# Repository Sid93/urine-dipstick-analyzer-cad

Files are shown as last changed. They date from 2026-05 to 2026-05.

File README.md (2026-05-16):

# Urine Dipstick Analyzer

> Open-source urine dipstick analyzer using ESP32-S3 + computer vision.







## What it does

A self-contained device that reads off-the-shelf 10-parameter urine dipsticks
(glucose, ketones, bilirubin, blood, pH, protein, urobilinogen, nitrite,
leukocytes, specific gravity) using a calibrated colorimetric pipeline. A
white + UV LED ring illuminates the strip, an OV2640 camera captures the
reaction pads, and an ESP32-S3 runs per-pad ROI analysis against a factory
calibration set anchored to an X-Rite ColorChecker Nano. Results are shown
on a 2.4" ILI9341 display, logged to SD, and optionally streamed over Wi-Fi.
Total BOM is approximately USD 330 in single-unit quantities.

## Photos and drawings

Mechanical drawings (PDF) for every printed/machined part live in
[`drawings/`](drawings/). 3D models in STEP and STL are in the project root
(`im_enclosure_base.*`, `enclosure_cover.*`, `camera_led_mount.*`,
`scanner_mount.*`, `vent_grill.*`, `im_tray.*`, `internal_wire_frame.*`).
Schematic render: [`schematic_render.png`](schematic_render.png).

## Hardware overview

| Subsystem | Part | Notes |
|---|---|---|
| MCU | ESP32-S3-DevKitC-1-N8R8 | 8 MB flash, 8 MB OPI PSRAM, dual-core |
| Camera | OV2640 (DVP) | hardware DVP on ESP32-S3 |
| Display | 2.4" ILI9341 SPI TFT | 320 x 240, Adafruit_ILI9341 driver |
| Illumination | White + 365 nm UV LEDs | constant-current via PMOS |
| Strip transport | NEMA-8 stepper + A4988 | AccelStepper-driven |
| Environment | SHT31 (T/RH), BH1750 (lux), DS3231 (RTC) | I2C bus |
| Power | Single 18650 + MCP73833 charger + MAX17048 fuel gauge | 3.7 V Li-ion |
| Enclosure | FDM PETG, M2.5 fasteners | STEP files in repo root |
| BOM cost | ~USD 330 | single-unit, see `BOM.csv` |

## Repository structure

```
.
├── README.md                      this file
├── LICENSE                        MIT
├── ASSEMBLY_GUIDE.md              SMT solder order, harnesses, mech build
├── BUILD_REPORT.md / _v2.md       generation pass logs
├── BOM.csv / BOM.pdf              bill of materials with MPNs
├── calibration.json               factory calibration (10 pads, 24-patch ref)
├── urine_dipstick_analyzer.*      KiCad project (sch + pcb + pro)
├── schematic_render.png           SVG-rendered schematic preview
├── generate_*.py                  reproducible build scripts (sch/pcb/cad/bom/drawings)
├── route_pcb.py                   programmatic auto-router for PCB1
├── drawings/                      mechanical PDFs
├── gerbers/                       fab-ready gerbers + drill (PCB1)
├── gerbers.zip                    zipped fab package
├── firmware/urine_dipstick_analyzer/   PlatformIO project + .ino + .h modules
├── *.step / *.stl                 mechanical 3D models (7 parts)
```

## Quick start

```bash
# 1. Clone
git clone https://github.com/Sid93/urine-dipstick-analyzer-cad.git
cd urine-dipstick-analyzer-cad

# 2. Install PlatformIO
pip3 install --user platformio

# 3. Build and flash the ESP32-S3
cd firmware/urine_dipstick_analyzer
pio run -t upload
pio device monitor
```

## Build the prototype

Full step-by-step build instructions live in two documents:

- [`BUILD_REPORT.md`](BUILD_REPORT.md) — design rationale, optical/colorimetric
  pipeline, per-subsystem reasoning.
- [`ASSEMBLY_GUIDE.md`](ASSEMBLY_GUIDE.md) — SMT solder order with bring-up
  tests, harness diagrams, mechanical assembly order, first-boot checklist,
  troubleshooting matrix.

## Project status

What works:

- Schematic and BOM are complete with manufacturer part numbers.
- PCB1 (power-distribution hub) is laid out, programmatically routed, and
  fab-ready gerbers are in `gerbers/`.
- Firmware compiles for ESP32-S3 (PlatformIO project, modular `.h` headers).
- Mechanical CAD is complete (STEP + STL for all 7 parts) with PDF drawings.
- Calibration JSON includes a full 24-patch ColorChecker reference and
  per-pad polynomial coefficients.

What is incomplete or known-issue:

- The PCB router is a simple Manhattan-MST router with naive crossing
  detection — it produces a manufacturable layout but not an optimized one.
  Recommend a manual review pass in KiCad and DRC run before fabricating.
- A few GPIO collisions in `firmware/urine_dipstick_analyzer/config.h` were
  flagged in v2 build report; some are now fixed in commit c849104 but a
  full strapping-pin audit is still recommended.
- Calibration values are realistic placeholders. The in-firmware
  `/calibrate` routine MUST be re-run with a real ColorChecker Nano under
  integrated illumination before any meaningful measurement.
- No clinical validation has been performed.

## Regulatory disclaimer

**This device is for research and educational use only. It is NOT a medical
device. It has not been evaluated or cleared by the U.S. FDA, the European
CE/IVDR process, or India's CDSCO.** In India, any in-vitro diagnostic
device intended for sale or clinical use requires CDSCO approval under the
Medical Devices Rules, 2017. Equivalent regulation applies in every other
jurisdiction. Do not use the output of this device to make clinical or
treatment decisions for yourself or anyone else. The authors and
contributors accept no liability for any use of this hardware or software.

## License

This project is licensed under the [MIT License](LICENSE).

## Citation

If you use this work in academic publications, please cite:

```bibtex
@misc{saboo2026urinedipstick,
  author       = {Saboo, Siddhant},
  title        = {Open-source Urine Dipstick Analyzer (ESP32-S3 + Computer Vision)},
  year         = {2026},
  howpublished = {\url{https://github.com/Sid93/urine-dipstick-analyzer-cad}},
  note         = {Research prototype, not a medical device}
}
```

## Acknowledgments

Built with the open-source ecosystem: KiCad 10, PlatformIO, the Espressif
Arduino core, Adafruit's GFX/ILI9341/BusIO/SHT31 libraries, Mike McCauley's
AccelStepper, Christopher Laws's BH1750 driver, Benoit Blanchon's
ArduinoJson, the X-Rite ColorChecker reference data, and Anthropic's
Claude for the agentic generation passes that produced the CAD, schematic,
PCB, gerbers, BOM, drawings, firmware scaffolding, and assembly guide.

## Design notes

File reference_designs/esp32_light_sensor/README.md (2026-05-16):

# ESP32-WROOM-32E + BH1750FVI Reference Design

A small, production-grade hardware reference for an ESP32 + ambient-light
sensor board, intended as a teaching example for the EE practices that
separate a hobby breakout from a manufacturable product.

The schematic includes USB-C input with full protection (polyfuse, TVS,
ESD diode array, reverse-polarity P-MOSFET), an AMS1117-3.3 LDO with
proper input/output decoupling, a ferrite-isolated clean rail to the ESP32,
correct strapping pins, EN reset RC, a 6-pin UART programming header, and
a BH1750FVI light sensor on I2C with pull-ups and an optional DNP EMI
filter.

## Contents

| File | Purpose |
| --- | --- |
| `generate_schematic.py` | Python generator (KiCad 8/9 compatible)  |
| `esp32_light_sensor.kicad_sch`| Generated schematic |
| `esp32_light_sensor.kicad_pro`| Project file with ERC severity overrides |
| `BOM.csv` | Full bill of materials with MPNs |
| `DESIGN_NOTES.md` | ~3000 word engineering write-up |
| `LAYOUT_NOTES.md` | PCB layout directives |
| `erc.txt` | ERC report (0 errors, 2 warnings) |

## Regenerating the Schematic

```bash
cd reference_designs/esp32_light_sensor
python3 generate_schematic.py
```

The script writes `esp32_light_sensor.kicad_sch` in this directory and
prints a summary of the output (line count, symbol/wire counts, file size).
It has no Python dependencies beyond the standard library.

## Opening in KiCad

```bash
open esp32_light_sensor.kicad_pro
```

The accompanying `.kicad_pro` file pre-loads ERC severity overrides
appropriate for a programmatically generated schematic (passive pins driven
through net-labels rather than wired junctions are downgraded from "error"
to "ignore").

## Running ERC from the Command Line

```bash
/Applications/KiCad.app/Contents/MacOS/kicad-cli sch erc \
  --output erc.txt esp32_light_sensor.kicad_sch
```

Expected result: 0 errors, 2 warnings (cosmetic - same name on local
and global label intentionally, for net continuity across visual gaps).

## Design Targets

- **Power:** 5 V USB-C in, 3.3 V at 800 mA out, idle <100 mA, full TX peak
  ~500 mA.
- **Protection:** IEC 61000-4-2 level 4 on USB (USBLC6), reverse polarity,
  500 mA polyfuse, 5 V TVS.
- **Sensor:** BH1750FVI, I2C at 400 kHz, address 0x23, 1-65535 lux range,
  +-20% accuracy.
- **Cost:** ~$9.30 at single-board qty, drops to ~$6.50 at qty 100.

## Relation to the Parent Project

This board lives inside the
[urine-dipstick-analyzer-cad](https://github.com/Sid93/urine-dipstick-analyzer-cad)
repo as a reference example. The parent project is a more ambitious
ESP32-S3 + camera + multi-sensor system; this design is the minimum
viable foundation those bigger boards build on top of. The
`generate_schematic.py` here re-uses the helper-function pattern from
the parent `generate_schematic.py` at the repo root.

## License

Same as the parent repo (see `../../LICENSE`).

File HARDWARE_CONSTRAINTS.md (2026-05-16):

# Hardware Constraints — ESP32-S3 GPIO Budget Analysis

The current design uses 37 GPIO signals on a module that has ~34 truly-available pins
once OPI flash+PSRAM and USB-CDC are accounted for. Two structural conflicts remain
and require an architectural decision, not pin shuffling.

## Conflict #1 — USB-CDC vs GPIO 19/20

| Pin | Conflicting use | Why |
|---|---|---|
| GPIO 19 | USB D− (native USB) **AND** `I2C_SDA` | `platformio.ini` enables `ARDUINO_USB_CDC_ON_BOOT=1` |
| GPIO 20 | USB D+ (native USB) **AND** `UV_GATE` | Same |

If USB-CDC is initialized, the USB peripheral takes electrical control of GPIO 19/20
and any I²C or GPIO traffic on these pins will fail. UART0 (GPIO 43/44) is also
unavailable because `BUZZER=43` and `HEATER_GATE=44`. Result: there is no clean
programming path **and** I²C+UV control simultaneously.

## Conflict #2 — OPI PSRAM vs GPIO 33-37

The chosen module is **ESP32-S3-WROOM-1-N8R8** = 8 MB flash + **8 MB octal PSRAM**.
OPI PSRAM consumes 8 pins: GPIO 26-32 (flash overlap) and GPIO 33-37 (data).

| Pin | Conflicting use | Why |
|---|---|---|
| GPIO 35 | OPI PSRAM D5 **AND** `CAM_VSYNC` | OPI PSRAM data |
| GPIO 36 | OPI PSRAM D6 **AND** `CAM_HREF` | OPI PSRAM data |
| GPIO 37 | OPI PSRAM D7 **AND** `CAM_PCLK` | OPI PSRAM data |

Camera VSYNC/HREF/PCLK are bus-critical edge-triggered signals — they cannot share
pins with PSRAM. If PSRAM is enabled, the camera bus will not work, and disabling
PSRAM breaks image-buffer allocation for a 2MP camera (need ≥ 2 MB heap for one frame
@ JPEG, ≥ 4 MB for RGB565). Internal RAM is only 512 KB.

---

## Three Resolution Paths

### Path A — Module swap to ESP32-S3-WROOM-1-N16R8V (QSPI PSRAM)

Drop-in pin-compatible module:
- 16 MB flash (was 8)
- 8 MB **quad** PSRAM (was octal) → only uses 4 pins (26-32 area), **frees GPIO 33-37**
- Slightly higher BOM cost: $6 → $8 (+$2)

**Fixes:** Conflict #2 entirely.
**Doesn't fix:** Conflict #1 (USB-CDC still steals GPIO 19/20).

### Path B — Add a PCA9555 I²C I/O expander (and Path A)

16-channel I²C-controlled GPIO expander, ~$1.20.
Move all slow switching signals to the expander:

| Signal | From ESP32 | To PCA9555 |
|---|---|---|
| FAN_GATE | GPIO 2 | EXP_P0 |
| HEATER_GATE | GPIO 44 | EXP_P1 |
| UV_GATE | GPIO 20 | EXP_P2 |
| WHITE_LED | GPIO 6 | EXP_P3 |
| BUZZER | GPIO 43 | EXP_P4 |
| REED_SWITCH | GPIO 21 | EXP_P5 (input) |
| LIMIT_SW | GPIO 42 | EXP_P6 (input) |
| BARCODE_TX | GPIO 0 | (keep — UART must stay on real GPIO) |
| BARCODE_RX | GPIO 17 | (keep — UART) |

This frees **GPIO 2, 6, 20, 21, 42, 43, 44** = **7 GPIOs**. We can then:
- Move I²C off GPIO 19 to GPIO 2 (SDA) + GPIO 42 (SCL), freeing 19
- Move UV_GATE off GPIO 20 (now on expander)
- Restore RGB_BLUE on GPIO 17 (move BARCODE_RX to GPIO 21)
- Re-enable Serial UART debug on GPIO 43/44

**Fixes:** Both conflicts.
**Cost:** +$1.20 BOM + PCB redesign + firmware refactor (~200 lines added).
**Tradeoff:** ~1 ms extra latency on switched signals via I²C — irrelevant for fan/heater/UV/buzzer, fine for limit/reed at typical poll rates.

### Path C — Accept conflicts as software constraints

Keep hardware unchanged. Add firmware safeguards:
- Disable USB-CDC at runtime once boot is complete (`Serial.end()` + reconfigure GPIO 19/20)
- Disable OPI PSRAM entirely (no big image buffers — limits camera capture to thumbnail JPEGs in heap)

**Fixes:** Symptomatic only.
**Cost:** No BOM/PCB changes.
**Tradeoff:** Lose USB serial debug capability after boot; lose PSRAM (camera reduced to ~640×480 JPEG only, max ~80 KB per frame in heap).

---

## Recommendation

**Path B (PCA9555 + module swap)** is the production-grade answer. It costs +$3.20 BOM
and adds two days of work (schematic + PCB + firmware), but produces a board that
actually meets the feature spec without runtime workarounds.

Path A alone is a quick win that fixes the camera conflict — adequate if you accept
that USB programming will work but USB-Serial debug after boot will require external
UART (CH340/CP2102 on GPIO 43/44 after re-freeing them via Path B).

Path C is what you'd ship if the prototype must move tomorrow and you'll respin v2
later with Path B.

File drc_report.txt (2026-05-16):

** Drc report for urine_dipstick_analyzer.kicad_pcb **
** Created on 2026-05-16T12:09:34 **
** Report includes: Errors, Warnings **

** Found 177 DRC violations **
[tracks_crossing]: Tracks crossing
    Local override; error
    @(37.4000 mm, 12.9750 mm): Track [SCL] on F.Cu, length 4.2250 mm
    @(34.6000 mm, 12.9750 mm): Track [SDA] on F.Cu, length 3.4250 mm
[tracks_crossing]: Tracks crossing
    Local override; error
    @(25.0500 mm, 18.0000 mm): Track [+3V3] on F.Cu, length 9.8750 mm
    @(21.0500 mm, 13.0000 mm): Track [VBAT] on F.Cu, length 5.0000 mm
[tracks_crossing]: Tracks crossing
    Local override; error
    @(21.0500 mm, 18.0000 mm): Track [VBAT] on F.Cu, length 7.8750 mm
    @(15.1750 mm, 18.0000 mm): Track [+3V3] on F.Cu, length 0.0000 mm
[tracks_crossing]: Tracks crossing
    Local override; error
    @(31.7500 mm, 12.0000 mm): Track [SDA] on F.Cu, length 13.5000 mm
    @(25.1750 mm, 14.0000 mm): Track [VBAT] on F.Cu, length 9.4250 mm
[tracks_crossing]: Tracks crossing
    Local override; error
    @(34.2500 mm, 12.0000 mm): Track [SCL] on F.Cu, length 13.5000 mm
    @(34.6000 mm, 12.9750 mm): Track [SDA] on F.Cu, length 3.4250 mm
[tracks_crossing]: Tracks crossing
    Local override; error
    @(33.1750 mm, 12.9750 mm): Track [SCL] on F.Cu, length 0.9750 mm
    @(34.6000 mm, 12.9750 mm): Track [SDA] on F.Cu, length 3.4250 mm
[shorting_items]: Items shorting two nets (nets VBAT and +3V3)
    Local override; error
    @(34.6000 mm, 14.0000 mm): Track [VBAT] on F.Cu, length 2.3250 mm
    @(34.8250 mm, 12.0000 mm): Via [+3V3] on F.Cu - B.Cu
[shorting_items]: Items shorting two nets (nets +3V3 and SCL)
    Local override; error
    @(32.8250 mm, 12.0000 mm): Via [+3V3] on F.Cu - B.Cu
    @(33.1750 mm, 12.0000 mm): Pad 1 [SCL] of R2 on F.Cu
[shorting_items]: Items shorting two nets (nets +3V3 and VBAT)
    Local override; error
    @(34.8250 mm, 12.0000 mm): Via [+3V3] on F.Cu - B.Cu
    @(34.6000 mm, 11.6750 mm): Track [VBAT] on F.Cu, length 2.8000 mm
[shorting_items]: Items shorting two nets (nets +3V3 and VBAT)
    Local override; error
    @(34.8250 mm, 12.0000 mm): Via [+3V3] on F.Cu - B.Cu
    @(34.6000 mm, 11.6750 mm): Track [VBAT] on F.Cu, length 0.5750 mm
[shorting_items]: Items shorting two nets (nets VBAT and +3V3)
    Local override; error
    @(35.1750 mm, 11.6750 mm): Track [VBAT] on F.Cu, length 4.3250 mm
    @(34.8250 mm, 12.0000 mm): Via [+3V3] on F.Cu - B.Cu
[shorting_items]: Items shorting two nets (nets VBUS and )
    Local override; error
    @(12.0000 mm, 6.7300 mm): Track [VBUS] on F.Cu, length 1.2700 mm
    @(11.8100 mm, 6.7300 mm): PTH pad 11 [<no net>] of U1a
[clearance]: Clearance violation ( clearance 0.2000 mm; actual 0.1625 mm)
    Local override; error
    @(30.9500 mm, 18.0000 mm): Pad 2 [GND] of CB4 on F.Cu
    @(31.7500 mm, 12.0000 mm): Track [SDA] on F.Cu, length 13.5000 mm
[shorting_items]: Items shorting two nets (nets SCL and VBAT)
    Local override; error
    @(33.1750 mm, 12.0000 mm): Track [SCL] on F.Cu, length 1.0750 mm
    @(34.6000 mm, 11.6750 mm): Pad 2 [VBAT] of U4 on F.Cu
[shorting_items]: Items shorting two nets (nets  and VBAT)
    Local override; error
    @(3.0000 mm, 27.0000 mm): NPTH pad of MH3
    @(4.7500 mm, 18.0000 mm): Track [VBAT] on F.Cu, length 7.5000 mm
[shorting_items]: Items shorting two nets (nets VBAT and SCL)
    Local override; error
    @(34.6000 mm, 11.6750 mm): Pad 2 [VBAT] of U4 on F.Cu
    @(34.2500 mm, 12.0000 mm): Track [SCL] on F.Cu, length 13.5000 mm
[shorting_items]: Items shorting two nets (nets VBUS and )
    Local override; error
    @(1.6500 mm, 6.7300 mm): Track [VBUS] on F.Cu, length 10.3500 mm
    @(4.1900 mm, 6.7300 mm): PTH pad 5 [<no net>] of U1a
[shorting_items]: Items shorting two nets (nets GND and +5V)
    Local override; error
    @(30.9500 mm, 18.0000 mm): Pad 2 [GND] of CB4 on F.Cu
    @(29.0500 mm, 18.0000 mm): Track [+5V] on F.Cu, length 2.1250 mm
[clearance]: Clearance violation ( clearance 0.2000 mm; actual 0.1000 mm)
    Local override; error
    @(33.1750 mm, 18.0000 mm): Track [+9V] on B.Cu, length 7.5000 mm
    @(32.8250 mm, 18.0000 mm): Track [+3V3] on B.Cu, length 6.0000 mm
[shorting_items]: Items shorting two nets (nets VMOT and GND)
    Local override; error
    @(36.5250 mm, 22.0000 mm): Track [VMOT] on F.Cu, length 4.2250 mm
    @(39.4750 mm, 22.0000 mm): Pad 2 [GND] of CB5 on F.Cu
[shorting_items]: Items shorting two nets (nets CHRG_STAT and VBUS)
    Local override; error
    @(20.5500 mm, 11.0000 mm): Via [CHRG_STAT] on F.Cu - B.Cu
    @(17.1750 mm, 11.0000 mm): Track [VBUS] on F.Cu, length 6.2750 mm
[clearance]: Clearance violation ( clearance 0.2000 mm; actual 0.0500 mm)
    Local override; error
    @(33.1750 mm, 25.5000 mm): Track [+9V] on B.Cu, length 19.4250 mm
    @(34.2500 mm, 25.5000 mm): PTH pad 2 [SCL] of J4
[shorting_items]: Items shorting two nets (nets +3V3 and GND)
    Local override; error
    @(25.0500 mm, 18.0000 mm): Track [+3V3] on F.Cu, length 2.3000 mm
    @(22.9500 mm, 18.0000 mm): Pad 2 [GND] of CB2 on F.Cu
[shorting_items]: Items shorting two nets (nets +3V3 and GND)
    Local override; error
    @(22.7500 mm, 18.0000 mm): Track [+3V3] on F.Cu, length 7.5000 mm
    @(22.9500 mm, 18.0000 mm): Pad 2 [GND] of CB2 on F.Cu
[shorting_items]: Items shorting two nets (nets  and VBUS)
    Local override; error
    @(16.8900 mm, 9.2700 mm): PTH pad 16 [<no net>] of U1a
    @(17.1750 mm, 8.0000 mm): Track [VBUS] on F.Cu, length 6.0000 mm
[shorting_items]: Items shorting two nets (nets +3V3 and GND)
    Local override; error
    @(25.0500 mm, 18.0000 mm): Track [+3V3] on F.Cu, length 9.8750 mm
    @(22.9500 mm, 18.0000 mm): Pad 2 [GND] of CB2 on F.Cu
[shorting_items]: Items shorting two nets (nets GND and +3V3)
    Local override; error
    @(14.8250 mm, 18.0000 mm): Pad 2 [GND] of C5 on F.Cu
    @(15.1750 mm, 18.0000 mm): Track [+3V3] on F.Cu, length 0.0000 mm
[clearance]: Clearance violation ( clearance 0.2000 mm; actual 0.1000 mm)
    Local override; error
    @(33.1750 mm, 18.0000 mm): Track [+9V] on B.Cu, length 7.5000 mm
    @(25.0500 mm, 18.0000 mm): Track [+3V3] on B.Cu, length 7.7750 mm
[shorting_items]: Items shorting two nets (nets VBAT and VBUS)
    Local override; error
    @(21.0500 mm, 18.0000 mm): Track [VBAT] on F.Cu, length 7.8750 mm
    @(17.0500 mm, 18.0000 mm): Via [VBUS] on F.Cu - B.Cu
[shorting_items]: Items shorting two nets (nets +3V3 and VBAT)
    Local override; error
    @(34.8250 mm, 12.0000 mm): Via [+3V3] on F.Cu - B.Cu
    @(34.6000 mm, 11.6750 mm): Pad 2 [VBAT] of U4 on F.Cu
[shorting_items]: Items shorting two nets (nets +9V and +3V3)
    Local override; error
    @(33.1750 mm, 18.0000 mm): Via [+9V] on F.Cu - B.Cu
    @(32.8250 mm, 18.0000 mm): Track [+3V3] on B.Cu, length 6.0000 mm
[shorting_items]: Items shorting two nets (nets VBAT and +3V3)
    Local override; error
    @(34.6000 mm, 11.6750 mm): Track [VBAT] on F.Cu, length 2.8000 mm
    @(34.8250 mm, 12.0000 mm): Via [+3V3] on F.Cu - B.Cu
[shorting_items]: Items shorting two nets (nets SCL and +3V3)
    Local override; error
    @(33.1750 mm, 12.0000 mm): Pad 1 [SCL] of R2 on F.Cu
    @(32.8250 mm, 12.0000 mm): Via [+3V3] on F.Cu - B.Cu
[shorting_items]: Items shorting two nets (nets GND and +3V3)
    Local override; error
    @(36.8250 mm, 16.0000 mm): Pad 2 [GND] of C3 on F.Cu
    @(37.1750 mm, 16.0000 mm): Via [+3V3] on F.Cu - B.Cu
[clearance]: Clearance violation ( clearance 0.2000 mm; actual 0.0750 mm)
    Local override; error
    @(20.5500 mm, 11.5000 mm): Via [CHRG_STAT] on F.Cu - B.Cu
    @(17.1750 mm, 11.0000 mm): Track [VBUS] on F.Cu, length 6.2750 mm
[shorting_items]: Items shorting two nets (nets GND and +9V)
    Local override; error
    @(32.8250 mm, 18.0000 mm): Pad 2 [GND] of C7 on F.Cu
    @(33.1750 mm, 18.0000 mm): Via [+9V] on F.Cu - B.Cu
[shorting_items]: Items shorting two nets (nets +9V and +3V3)
    Local override; error
    @(33.1750 mm, 18.0000 mm): Via [+9V] on F.Cu - B.Cu
    @(25.0500 mm, 18.0000 mm): Track [+3V3] on B.Cu, length 7.7750 mm
[clearance]: Clearance violation ( clearance 0.2000 mm; actual 0.0000 mm)
    Local override; error
    @(3.0000 mm, 27.0000 mm): NPTH pad of MH3
    @(4.7500 mm, 25.5000 mm): PTH pad 1 [VBAT] of J1
[shorting_items]: Items shorting two nets (nets +3V3 and GND)
    Local override; error
    @(37.1750 mm, 16.0000 mm): Pad 1 [+3V3] of C4 on F.Cu
    @(36.8250 mm, 16.0000 mm): Pad 2 [GND] of C3 on F.Cu
[shorting_items]: Items shorting two nets (nets VBUS and GND)
    Local override; error
    @(17.0500 mm, 18.0000 mm): Pad 1 [VBUS] of CB1 on F.Cu
    @(16.8250 mm, 18.0000 mm): Pad 2 [GND] of C6 on F.Cu
[shorting_items]: Items shorting two nets (nets GND and +3V3)
    Local override; error
    @(14.8250 mm, 18.0000 mm): Pad 2 [GND] of C5 on F.Cu
    @(15.1750 mm, 18.0000 mm): Pad 1 [+3V3] of C6 on F.Cu
[shorting_items]: Items shorting two nets (nets SCL and +3V3)
    Local override; error
    @(33.1750 mm, 12.0000 mm): Pad 1 [SCL] of R2 on F.Cu
    @(32.8250 mm, 12.0000 mm): Pad 2 [+3V3] of R1 on F.Cu
[hole_clearance]: Hole clearance violation (board setup constraints hole clearance 0.2500 mm; actual 0.0000 mm)
    Rule: board setup constraints hole; error
    @(16.8250 mm, 18.0000 mm): Pad 2 [GND] of C6 on F.Cu
    @(17.0500 mm, 18.0000 mm): Via [VBUS] on F.Cu - B.Cu
[hole_clearance]: Hole clearance violation (board setup constraints hole clearance 0.2500 mm; actual 0.0000 mm)
    Rule: board setup constraints hole; error
    @(33.1750 mm, 12.0000 mm): Pad 1 [SCL] of R2 on F.Cu
    @(32.8250 mm, 12.0000 mm): Via [+3V3] on F.Cu - B.Cu
[hole_clearance]: Hole clearance violation (board setup constraints hole clearance 0.2500 mm; actual 0.0000 mm)
    Rule: board setup constraints hole; error
    @(33.1750 mm, 12.0000 mm): Pad 1 [SCL] of R2 on F.Cu
    @(32.8250 mm, 12.0000 mm): Via [+3V3] on F.Cu - B.Cu
[shorting_items]: Items shorting two nets (nets +3V3 and VBAT)
    Local override; error
    @(34.8250 mm, 12.0000 mm): Pad 2 [+3V3] of R2 on F.Cu
    @(34.6000 mm, 11.6750 mm): Pad 2 [VBAT] of U4 on F.Cu
[shorting_items]: Items shorting two nets (nets +3V3 and GND)
    Local override; error
    @(34.8250 mm, 12.0000 mm): Pad 2 [+3V3] of R2 on F.Cu
    @(34.6000 mm, 12.3250 mm): Pad 3 [GND] of U4 on F.Cu
[shorting_items]: Items shorting two nets (nets +5V and GND)
    Local override; error
    @(31.1750 mm, 18.0000 mm): Pad 1 [+5V] of C7 on F.Cu
    @(30.9500 mm, 18.0000 mm): Pad 2 [GND] of CB4 on F.Cu
[hole_clearance]: Hole clearance violation (board setup constraints hole clearance 0.2500 mm; actual 0.0000 mm)
    Rule: board setup constraints hole; error
    @(36.8250 mm, 16.0000 mm): Pad 2 [GND] of C3 on F.Cu
    @(37.1750 mm, 16.0000 mm): Via [+3V3] on F.Cu - B.Cu
[hole_clearance]: Hole clearance violation (board setup constraints hole clearance 0.2500 mm; actual 0.0000 mm)
    Rule: board setup constraints hole; error
    @(32.8250 mm, 18.0000 mm): Pad 2 [GND] of C7 on F.Cu
    @(33.1750 mm, 18.0000 mm): Via [+9V] on F.Cu - B.Cu
[shorting_items]: Items shorting two nets (nets GND and +9V)
    Local override; error
    @(32.8250 mm, 18.0000 mm): Pad 2 [GND] of C7 on F.Cu
    @(33.1750 mm, 18.0000 mm): Pad 1 [+9V] of C8 on F.Cu
[clearance]: Clearance violation ( clearance 0.2000 mm; actual 0.0000 mm)
    Local override; error
    @(11.8100 mm, 6.7300 mm): PTH pad 11 [<no net>] of U1a
    @(12.0000 mm, 8.0000 mm): Pad 1 [VBUS] of F1 on F.Cu
[clearance]: Clearance violation ( clearance 0.2000 mm; actual 0.0000 mm)
    Local override; error
    @(11.8100 mm, 9.2700 mm): PTH pad 12 [<no net>] of U1a
    @(12.0000 mm, 8.0000 mm): Pad 1 [VBUS] of F1 on F.Cu
[clearance]: Clearance violation ( clearance 0.2000 mm; actual 0.0000 mm)
    Local override; error
    @(14.3500 mm, 6.7300 mm): PTH pad 13 [<no net>] of U1a
    @(16.0000 mm, 8.0000 mm): Pad 2 [VBUS] of F1 on F.Cu
[clearance]: Clearance violation ( clearance 0.2000 mm; actual 0.0000 mm)
    Local override; error
    @(14.3500 mm, 9.2700 mm): PTH pad 14 [<no net>] of U1a
    @(16.0000 mm, 8.0000 mm): Pad 2 [VBUS] of F1 on F.Cu
[clearance]: Clearance violation ( clearance 0.2000 mm; actual 0.0000 mm)
    Local override; error
    @(16.8900 mm, 6.7300 mm): PTH pad 15 [<no net>] of U1a
    @(16.0000 mm, 8.0000 mm): Pad 2 [VBUS] of F1 on F.Cu
[clearance]: Clearance violation ( clearance 0.2000 mm; actual 0.0000 mm)
    Local override; error
    @(16.8900 mm, 9.2700 mm): PTH pad 16 [<no net>] of U1a
    @(16.0000 mm, 8.0000 mm): Pad 2 [VBUS] of F1 on F.Cu
[hole_clearance]: Hole clearance violation (board setup constraints hole clearance 0.2500 mm; actual 0.2000 mm)
    Rule: board setup constraints hole; error
    @(20.5500 mm, 12.0000 mm): Pad 3 [PG] of U1 on F.Cu
    @(20.5500 mm, 11.5000 mm): Via [CHRG_STAT] on F.Cu - B.Cu
[hole_clearance]: Hole clearance violation (board setup constraints hole clearance 0.2500 mm; actual 0.0000 mm)
    Rule: board setup constraints hole; error
    @(34.6000 mm, 11.6750 mm): Pad 2 [VBAT] of U4 on F.Cu
    @(34.8250 mm, 12.0000 mm): Via [+3V3] on F.Cu - B.Cu
[hole_clearance]: Hole clearance violation (board setup constraints hole clearance 0.2500 mm; actual 0.0000 mm)
    Rule: board setup constraints hole; error
    @(34.6000 mm, 11.6750 mm): Pad 2 [VBAT] of U4 on F.Cu
    @(34.8250 mm, 12.0000 mm): Via [+3V3] on F.Cu - B.Cu
[hole_clearance]: Hole clearance violation (board setup constraints hole clearance 0.2500 mm; actual 0.0000 mm)
    Rule: board setup constraints hole; error
    @(34.6000 mm, 12.3250 mm): Pad 3 [GND] of U4 on F.Cu
    @(34.8250 mm, 12.0000 mm): Via [+3V3] on F.Cu - B.Cu
[hole_clearance]: Hole clearance violation (board setup constraints hole clearance 0.2500 mm; actual 0.0000 mm)
    Rule: board setup constraints hole; error
    @(34.6000 mm, 12.3250 mm): Pad 3 [GND] of U4 on F.Cu
    @(34.8250 mm, 12.0000 mm): Via [+3V3] on F.Cu - B.Cu
[copper_edge_clearance]: Board edge clearance violation (board setup constraints edge clearance 0.5000 mm; actual 0.0400 mm)
    Rule: board setup constraints edge; error
    @(0.0000 mm, 30.0000 mm): Segment on Edge.Cuts
    @(-0.8900 mm, 6.7300 mm): PTH pad 1 [GND] of U1a
[copper_edge_clearance]: Board edge clearance violation (board setup constraints edge clearance 0.5000 mm; actual 0.0400 mm)
    Rule: board setup constraints edge; error
    @(0.0000 mm, 30.0000 mm): Segment on Edge.Cuts
    @(-0.8900 mm, 9.2700 mm): PTH pad 2 [GND] of U1a
[solder_mask_bridge]: Front solder mask aperture bridges items with different nets
    Rule: board setup solder mask min width; error
    @(21.0500 mm, 18.0000 mm): Track [VBAT] on F.Cu, length 7.8750 mm
    @(18.9500 mm, 18.0000 mm): Pad 2 [GND] of CB1 on F.Cu
[solder_mask_bridge]: Front solder mask aperture bridges items with different nets
    Rule: board setup solder mask min width; error
    @(17.1750 mm, 8.0000 mm): Track [VBUS] on F.Cu, length 6.0000 mm
    @(16.8900 mm, 9.2700 mm): PTH pad 16 [<no net>] of U1a
[solder_mask_bridge]: Front solder mask aperture bridges items with different nets
    Rule: board setup solder mask min width; error
    @(21.0500 mm, 18.0000 mm): Track [VBAT] on F.Cu, length 7.8750 mm
    @(17.0500 mm, 18.0000 mm): Pad 1 [VBUS] of CB1 on F.Cu
[solder_mask_bridge]: Front solder mask aperture bridges items with different nets
    Rule: board setup solder mask min width; error
    @(11.8100 mm, 6.7300 mm): PTH pad 11 [<no net>] of U1a
    @(12.0000 mm, 8.0000 mm): Pad 1 [VBUS] of F1 on F.Cu
[solder_mask_bridge]: Front solder mask aperture bridges items with different nets
    Rule: board setup solder mask min width; error
    @(32.8250 mm, 18.0000 mm): Pad 2 [GND] of C7 on F.Cu
    @(33.1750 mm, 18.0000 mm): Pad 1 [+9V] of C8 on F.Cu
[solder_mask_bridge]: Front solder mask aperture bridges items with different nets
    Rule: board setup solder mask min width; error
    @(34.6000 mm, 11.6750 mm): Pad 2 [VBAT] of U4 on F.Cu
    @(34.8250 mm, 12.0000 mm): Pad 2 [+3V3] of R2 on F.Cu
[solder_mask_bridge]: Front solder mask aperture bridges items with different nets
    Rule: board setup solder mask min width; error
    @(30.9500 mm, 18.0000 mm): Pad 2 [GND] of CB4 on F.Cu
    @(31.1750 mm, 18.0000 mm): Pad 1 [+5V] of C7 on F.Cu
[solder_mask_bridge]: Front solder mask aperture bridges items with different nets
    Rule: board setup solder mask min width; error
    @(34.8250 mm, 12.0000 mm): Via [+3V3] on F.Cu - B.Cu
    @(34.6000 mm, 11.6750 mm): Pad 2 [VBAT] of U4 on F.Cu
[solder_mask_bridge]: Front solder mask aperture bridges items with different nets
    Rule: board setup solder mask min width; error
    @(21.0500 mm, 18.0000 mm): Track [VBAT] on F.Cu, length 7.8750 mm
    @(16.8250 mm, 18.0000 mm): Pad 2 [GND] of C6 on F.Cu
[solder_mask_bridge]: Front solder mask aperture bridges items with different nets
    Rule: board setup solder mask min width; error
    @(17.1750 mm, 11.0000 mm): Track [VBUS] on F.Cu, length 6.2750 mm
    @(20.5500 mm, 11.0000 mm): Pad 1 [CHRG_STAT] of U1 on F.Cu
[solder_mask_bridge]: Front solder mask aperture bridges items with different nets
    Rule: board setup solder mask min width; error
    @(21.0500 mm, 18.0000 mm): Track [VBAT] on F.Cu, length 7.8750 mm
    @(14.8250 mm, 18.0000 mm): Pad 2 [GND] of C5 on F.Cu
[solder_mask_bridge]: Front solder mask aperture bridges items with different nets
    Rule: board setup solder mask min width; error
    @(25.0500 mm, 18.0000 mm): Track [+3V3] on F.Cu, length 2.3000 mm
    @(22.9500 mm, 18.0000 mm): Pad 2 [GND] of CB2 on F.Cu
[solder_mask_bridge]: Front solder mask aperture bridges items with different nets
    Rule: board setup solder mask min width; error
    @(11.8100 mm, 9.2700 mm): PTH pad 12 [<no net>] of U1a
    @(12.0000 mm, 8.0000 mm): Pad 1 [VBUS] of F1 on F.Cu
[solder_mask_bridge]: Front solder mask aperture bridges items with different nets
    Rule: board setup solder mask min width; error
    @(32.8250 mm, 12.0000 mm): Pad 2 [+3V3] of R1 on F.Cu
    @(33.1750 mm, 12.0000 mm): Pad 1 [SCL] of R2 on F.Cu
[solder_mask_bridge]: Front solder mask aperture bridges items with different nets
    Rule: board setup solder mask min width; error
    @(36.8250 mm, 16.0000 mm): Pad 2 [GND] of C3 on F.Cu
    @(37.1750 mm, 16.0000 mm): Pad 1 [+3V3] of C4 on F.Cu
[solder_mask_bridge]: Front solder mask aperture bridges items with different nets
    Rule: board setup solder mask min width; error
    @(34.8250 mm, 12.0000 mm): Via [+3V3] on F.Cu - B.Cu
    @(34.6000 mm, 12.3250 mm): Pad 3 [GND] of U4 on F.Cu
[solder_mask_bridge]: Front solder mask aperture bridges items with different nets
    Rule: board setup solder mask min width; error
    @(34.6000 mm, 12.3250 mm): Pad 3 [GND] of U4 on F.Cu
    @(34.8250 mm, 12.0000 mm): Pad 2 [+3V3] of R2 on F.Cu
[solder_mask_bridge]: Front solder mask aperture bridges items with different nets
    Rule: board setup solder mask min width; error
    @(37.4000 mm, 12.9750 mm): Track [SCL] on F.Cu, length 4.2250 mm
    @(34.6000 mm, 12.9750 mm): Pad 4 [SDA] of U4 on F.Cu
[solder_mask_bridge]: Front solder mask aperture bridges items with different nets
    Rule: board setup solder mask min width; error
    @(21.0500 mm, 18.0000 mm): Track [VBAT] on F.Cu, length 7.8750 mm
    @(15.1750 mm, 18.0000 mm): Pad 1 [+3V3] of C6 on F.Cu
[solder_mask_bridge]: Front solder mask aperture bridges items with different nets
    Rule: board setup solder mask min width; error
    @(4.7500 mm, 25.5000 mm): PTH pad 1 [VBAT] of J1
    @(3.0000 mm, 27.0000 mm): NPTH pad of MH3
[solder_mask_bridge]: Front solder mask aperture bridges items with different nets
    Rule: board setup solder mask min width; error
    @(37.1750 mm, 16.0000 mm): Via [+3V3] on F.Cu - B.Cu
    @(36.8250 mm, 16.0000 mm): Pad 2 [GND] of C3 on F.Cu
[solder_mask_bridge]: Front solder mask aperture bridges items with different nets
    Rule: board setup solder mask min width; error
    @(22.7500 mm, 18.0000 mm): Track [+3V3] on F.Cu, length 7.5000 mm
    @(22.9500 mm, 18.0000 mm): Pad 2 [GND] of CB2 on F.Cu
[solder_mask_bridge]: Front solder mask aperture bridges items with different nets
    Rule: board setup solder mask min width; error
    @(25.1750 mm, 14.0000 mm): Track [VBAT] on F.Cu, length 9.4250 mm
    @(26.8250 mm, 14.0000 mm): Pad 2 [GND] of C2 on F.Cu
[solder_mask_bridge]: Front solder mask aperture bridges items with different nets
    Rule: board setup solder mask min width; error
    @(16.8900 mm, 6.7300 mm): PTH pad 15 [<no net>] of U1a
    @(16.0000 mm, 8.0000 mm): Pad 2 [VBUS] of F1 on F.Cu
[solder_mask_bridge]: Front solder mask aperture bridges items with different nets
    Rule: board setup solder mask min width; error
    @(14.8250 mm, 18.0000 mm): Pad 2 [GND] of C5 on F.Cu
    @(15.1750 mm, 18.0000 mm): Pad 1 [+3V3] of C6 on F.Cu
[solder_mask_bridge]: Front solder mask aperture bridges items with different nets
    Rule: board setup solder mask min width; error
    @(33.1750 mm, 18.0000 mm): Via [+9V] on F.Cu - B.Cu
    @(32.8250 mm, 18.0000 mm): Pad 2 [GND] of C7 on F.Cu
[solder_mask_bridge]: Front solder mask aperture bridges items with different nets
    Rule: board setup solder mask min width; error
    @(25.0500 mm, 18.0000 mm): Track [+3V3] on F.Cu, length 9.8750 mm
    @(18.9500 mm, 18.0000 mm): Pad 2 [GND] of CB1 on F.Cu
[solder_mask_bridge]: Front solder mask aperture bridges items with different nets
    Rule: board setup solder mask min width; error
    @(25.0500 mm, 18.0000 mm): Track [+3V3] on F.Cu, length 9.8750 mm
    @(21.0500 mm, 18.0000 mm): Pad 1 [VBAT] of CB2 on F.Cu
[solder_mask_bridge]: Rear solder mask aperture bridges items with different nets
    Rule: board setup solder mask min width; error
    @(4.7500 mm, 25.5000 mm): PTH pad 1 [VBAT] of J1
    @(3.0000 mm, 27.0000 mm): NPTH pad of MH3
[solder_mask_bridge]: Front solder mask aperture bridges items with different nets
    Rule: board setup solder mask min width; error
    @(34.6000 mm, 14.0000 mm): Track [VBAT] on F.Cu, length 2.3250 mm
    @(34.8250 mm, 12.0000 mm): Pad 2 [+3V3] of R2 on F.Cu
[solder_mask_bridge]: Front solder mask aperture bridges items with different nets
    Rule: board setup solder mask min width; error
    @(16.0000 mm, 8.0000 mm): Pad 2 [VBUS] of F1 on F.Cu
    @(16.8900 mm, 9.2700 mm): PTH pad 16 [<no net>] of U1a
[solder_mask_bridge]: Front solder mask aperture bridges items with different nets
    Rule: board setup solder mask min width; error
    @(16.8250 mm, 18.0000 mm): Pad 2 [GND] of C6 on F.Cu
    @(17.0500 mm, 18.0000 mm): Pad 1 [VBUS] of CB1 on F.Cu
[solder_mask_bridge]: Front solder mask aperture bridges items with different nets
    Rule: board setup solder mask min width; error
    @(34.6000 mm, 14.0000 mm): Track [VBAT] on F.Cu, length 2.3250 mm
    @(34.6000 mm, 12.9750 mm): Pad 4 [SDA] of U4 on F.Cu
[solder_mask_bridge]: Front solder mask aperture bridges items with different nets
    Rule: board setup solder mask min width; error
    @(34.6000 mm, 14.0000 mm): Track [VBAT] on F.Cu, length 2.3250 mm
    @(34.6000 mm, 12.3250 mm): Pad 3 [GND] of U4 on F.Cu
[solder_mask_bridge]: Front solder mask aperture bridges items with different nets
    Rule: board setup solder mask min width; error
    @(25.0500 mm, 18.0000 mm): Track [+3V3] on F.Cu, length 9.8750 mm
    @(22.9500 mm, 18.0000 mm): Pad 2 [GND] of CB2 on F.Cu
[solder_mask_bridge]: Front solder mask aperture bridges items with different nets
    Rule: board setup solder mask min width; error
    @(33.1750 mm, 12.9750 mm): Track [SCL] on F.Cu, length 0.9750 mm
    @(32.8250 mm, 12.0000 mm): Pad 2 [+3V3] of R1 on F.Cu
[solder_mask_bridge]: Front solder mask aperture bridges items with different nets
    Rule: board setup solder mask min width; error
    @(34.6000 mm, 11.6750 mm): Track [VBAT] on F.Cu, length 2.8000 mm
    @(34.8250 mm, 12.0000 mm): Pad 2 [+3V3] of R2 on F.Cu
[solder_mask_bridge]: Front solder mask aperture bridges items with different nets
    Rule: board setup solder mask min width; error
    @(25.0500 mm, 18.0000 mm): Track [+3V3] on F.Cu, length 9.8750 mm
    @(17.0500 mm, 18.0000 mm): Pad 1 [VBUS] of CB1 on F.Cu
[solder_mask_bridge]: Front solder mask aperture bridges items with different nets
    Rule: board setup solder mask min width; error
    @(33.1750 mm, 12.0000 mm): Track [SCL] on F.Cu, length 1.0750 mm
    @(34.6000 mm, 11.6750 mm): Pad 2 [VBAT] of U4 on F.Cu
[solder_mask_bridge]: Front solder mask aperture bridges items with different nets
    Rule: board setup solder mask min width; error
    @(33.1750 mm, 12.0000 mm): Track [SCL] on F.Cu, length 1.0750 mm
    @(34.6000 mm, 12.3250 mm): Pad 3 [GND] of U4 on F.Cu
[solder_mask_bridge]: Front solder mask aperture bridges items with different nets
    Rule: board setup solder mask min width; error
    @(25.0500 mm, 18.0000 mm): Track [+3V3] on F.Cu, length 9.8750 mm
    @(16.8250 mm, 18.0000 mm): Pad 2 [GND] of C6 on F.Cu
[solder_mask_bridge]: Front solder mask aperture bridges items with different nets
    Rule: board setup solder mask min width; error
    @(33.1750 mm, 12.0000 mm): Track [SCL] on F.Cu, length 1.0750 mm
    @(32.8250 mm, 12.0000 mm): Pad 2 [+3V3] of R1 on F.Cu
[solder_mask_bridge]: Front solder mask aperture bridges items with different nets
    Rule: board setup solder mask min width; error
    @(25.0500 mm, 18.0000 mm): Track [+3V3] on F.Cu, length 9.8750 mm
    @(14.8250 mm, 18.0000 mm): Pad 2 [GND] of C5 on F.Cu
[solder_mask_bridge]: Front solder mask aperture bridges items with different nets
    Rule: board setup solder mask min width; error
    @(34.6000 mm, 11.6750 mm): Track [VBAT] on F.Cu, length 0.5750 mm
    @(34.8250 mm, 12.0000 mm): Pad 2 [+3V3] of R2 on F.Cu
[solder_mask_bridge]: Front solder mask aperture bridges items with different nets
    Rule: board setup solder mask min width; error
    @(15.1750 mm, 18.0000 mm): Track [+3V3] on F.Cu, length 0.0000 mm
    @(14.8250 mm, 18.0000 mm): Pad 2 [GND] of C5 on F.Cu
[solder_mask_bridge]: Front solder mask aperture bridges items with different nets
    Rule: board setup solder mask min width; error
    @(35.1750 mm, 11.6750 mm): Track [VBAT] on F.Cu, length 4.3250 mm
    @(34.8250 mm, 12.0000 mm): Pad 2 [+3V3] of R2 on F.Cu
[solder_mask_bridge]: Front solder mask aperture bridges items with different nets
    Rule: board setup solder mask min width; error
    @(34.2500 mm, 12.0000 mm): Track [SCL] on F.Cu, length 13.5000 mm
    @(34.6000 mm, 11.6750 mm): Pad 2 [VBAT] of U4 on F.Cu
[solder_mask_bridge]: Front solder mask aperture bridges items with different nets
    Rule: board setup solder mask min width; error
    @(4.7500 mm, 18.0000 mm): Track [VBAT] on F.Cu, length 7.5000 mm
    @(3.0000 mm, 27.0000 mm): NPTH pad of MH3
[solder_mask_bridge]: Front solder mask aperture bridges items with different nets
    Rule: board setup solder mask min width; error
    @(34.2500 mm, 12.0000 mm): Track [SCL] on F.Cu, length 13.5000 mm
    @(34.6000 mm, 12.9750 mm): Pad 4 [SDA] of U4 on F.Cu
[solder_mask_bridge]: Front solder mask aperture bridges items with different nets
    Rule: board setup solder mask min width; error
    @(34.2500 mm, 12.0000 mm): Track [SCL] on F.Cu, length 13.5000 mm
    @(34.6000 mm, 12.3250 mm): Pad 3 [GND] of U4 on F.Cu
[solder_mask_bridge]: Front solder mask aperture bridges items with different nets
    Rule: board setup solder mask min width; error
    @(1.6500 mm, 6.7300 mm): Track [VBUS] on F.Cu, length 10.3500 mm
    @(4.1900 mm, 6.7300 mm): PTH pad 5 [<no net>] of U1a
[solder_mask_bridge]: Front solder mask aperture bridges items with different nets
    Rule: board setup solder mask min width; error
    @(1.6500 mm, 6.7300 mm): Track [VBUS] on F.Cu, length 10.3500 mm
    @(6.7300 mm, 6.7300 mm): PTH pad 7 [<no net>] of U1a
[solder_mask_bridge]: Front solder mask aperture bridges items with different nets
    Rule: board setup solder mask min width; error
    @(29.0500 mm, 18.0000 mm): Track [+5V] on F.Cu, length 2.1250 mm
    @(30.9500 mm, 18.0000 mm): Pad 2 [GND] of CB4 on F.Cu
[solder_mask_bridge]: Front solder mask aperture bridges items with different nets
    Rule: board setup solder mask min width; error
    @(1.6500 mm, 6.7300 mm): Track [VBUS] on F.Cu, length 10.3500 mm
    @(9.2700 mm, 6.7300 mm): PTH pad 9 [<no net>] of U1a
[solder_mask_bridge]: Front solder mask aperture bridges items with different nets
    Rule: board setup solder mask min width; error
    @(36.5250 mm, 22.0000 mm): Track [VMOT] on F.Cu, length 4.2250 mm
    @(39.4750 mm, 22.0000 mm): Pad 2 [GND] of CB5 on F.Cu
[solder_mask_bridge]: Front solder mask aperture bridges items with different nets
    Rule: board setup solder mask min width; error
    @(1.6500 mm, 6.7300 mm): Track [VBUS] on F.Cu, length 10.3500 mm
    @(11.8100 mm, 6.7300 mm): PTH pad 11 [<no net>] of U1a
[solder_mask_bridge]: Rear solder mask aperture bridges items with different nets
    Rule: board setup solder mask min width; error
    @(33.1750 mm, 25.5000 mm): Track [+9V] on B.Cu, length 19.4250 mm
    @(16.2500 mm, 25.5000 mm): PTH pad 2 [GND] of J2
[solder_mask_bridge]: Front solder mask aperture bridges items with different nets
    Rule: board setup solder mask min width; error
    @(12.0000 mm, 6.7300 mm): Track [VBUS] on F.Cu, length 1.2700 mm
    @(11.8100 mm, 6.7300 mm): PTH pad 11 [<no net>] of U1a
[solder_mask_bridge]: Rear solder mask aperture bridges items with different nets
    Rule: board setup solder mask min width; error
    @(33.1750 mm, 25.5000 mm): Track [+9V] on B.Cu, length 19.4250 mm
    @(22.7500 mm, 25.5000 mm): PTH pad 1 [+3V3] of J3
[solder_mask_bridge]: Rear solder mask aperture bridges items with different nets
    Rule: board setup solder mask min width; error
    @(33.1750 mm, 25.5000 mm): Track [+9V] on B.Cu, length 19.4250 mm
    @(25.2500 mm, 25.5000 mm): PTH pad 2 [GND] of J3
[solder_mask_bridge]: Rear solder mask aperture bridges items with different nets
    Rule: board setup solder mask min width; error
    @(33.1750 mm, 25.5000 mm): Track [+9V] on B.Cu, length 19.4250 mm
    @(31.7500 mm, 25.5000 mm): PTH pad 1 [SDA] of J4
[solder_mask_bridge]: Front solder mask aperture bridges items with different nets
    Rule: board setup solder mask min width; error
    @(17.0500 mm, 18.0000 mm): Via [VBUS] on F.Cu - B.Cu
    @(16.8250 mm, 18.0000 mm): Pad 2 [GND] of C6 on F.Cu
[solder_mask_bridge]: Front solder mask aperture bridges items with different nets
    Rule: board setup solder mask min width; error
    @(32.8250 mm, 12.0000 mm): Via [+3V3] on F.Cu - B.Cu
    @(33.1750 mm, 12.0000 mm): Pad 1 [SCL] of R2 on F.Cu
[solder_mask_bridge]: Front solder mask aperture bridges items with different nets
    Rule: board setup solder mask min width; error
    @(32.8250 mm, 12.0000 mm): Via [+3V3] on F.Cu - B.Cu
    @(33.1750 mm, 12.0000 mm): Pad 1 [SCL] of R2 on F.Cu
[solder_mask_bridge]: Front solder mask aperture bridges items with different nets
    Rule: board setup solder mask min width; error
    @(34.8250 mm, 12.0000 mm): Via [+3V3] on F.Cu - B.Cu
    @(34.6000 mm, 11.6750 mm): Pad 2 [VBAT] of U4 on F.Cu
[solder_mask_bridge]: Front solder mask aperture bridges items with different nets
    Rule: board setup solder mask min width; error
    @(34.8250 mm, 12.0000 mm): Via [+3V3] on F.Cu - B.Cu
    @(34.6000 mm, 12.3250 mm): Pad 3 [GND] of U4 on F.Cu
[silk_edge_clearance]: Silkscreen clipped by board edge
    Rule: board setup constraints silk; warning
    @(0.0000 mm, 0.0000 mm): Segment on Edge.Cuts
    @(3.0000 mm, -0.5000 mm): Reference field of MH1
[silk_edge_clearance]: Silkscreen clipped by board edge
    Rule: board setup constraints silk; warning
    @(0.0000 mm, 0.0000 mm): Segment on Edge.Cuts
    @(47.0000 mm, -0.5000 mm): Reference field of MH2
[holes_co_located]: Drilled holes co-located
    Local override; warning
    @(32.8250 mm, 12.0000 mm): Via [+3V3] on F.Cu - B.Cu
    @(32.8250 mm, 12.0000 mm): Via [+3V3] on F.Cu - B.Cu
[holes_co_located]: Drilled holes co-located
    Local override; warning
    @(34.8250 mm, 12.0000 mm): Via [+3V3] on F.Cu - B.Cu
    @(34.8250 mm, 12.0000 mm): Via [+3V3] on F.Cu - B.Cu
[hole_to_hole]: Drilled hole too close to other hole (board setup constraints min 0.2495 mm; actual 0.2000 mm)
    Rule: board setup constraints; warning
    @(20.5500 mm, 11.5000 mm): Via [CHRG_STAT] on F.Cu - B.Cu
    @(20.5500 mm, 11.0000 mm): Via [CHRG_STAT] on F.Cu - B.Cu
[lib_footprint_mismatch]: Footprint 'MountingHole_2.7mm_M2.5' does not match copy in library 'MountingHole'
    Local override; warning
    @(3.0000 mm, 3.0000 mm): Footprint MH1
[lib_footprint_mismatch]: Footprint 'MountingHole_2.7mm_M2.5' does not match copy in library 'MountingHole'
    Local override; warning
    @(47.0000 mm, 3.0000 mm): Footprint MH2
[lib_footprint_mismatch]: Footprint 'MountingHole_2.7mm_M2.5' does not match copy in library 'MountingHole'
    Local override; warning
    @(3.0000 mm, 27.0000 mm): Footprint MH3
[lib_footprint_mismatch]: Footprint 'MountingHole_2.7mm_M2.5' does not match copy in library 'MountingHole'
    Local override; warning
    @(47.0000 mm, 27.0000 mm): Footprint MH4
[lib_footprint_mismatch]: Footprint 'PinHeader_2x08_P2.54mm_Vertical' does not match copy in library 'Connector_PinHeader_2.54mm'
    Local override; warning
    @(8.0000 mm, 8.0000 mm): Footprint U1a
[lib_footprint_mismatch]: Footprint 'MSOP-10_3x3mm_P0.5mm' does not match copy in library 'Package_SO'
    Local override; warning
    @(22.0000 mm, 12.0000 mm): Footprint U1
[lib_footprint_mismatch]: Footprint 'SOT-23-8' does not match copy in library 'Package_TO_SOT_SMD'
    Local override; warning
    @(36.0000 mm, 12.0000 mm): Footprint U4
[lib_footprint_issues]: The current configuration does not include the footprint library 'Fuse_SMD'
    Local override; warning
    @(14.0000 mm, 8.0000 mm): Footprint F1
[lib_footprint_mismatch]: Footprint 'C_0805_2012Metric' does not match copy in library 'Capacitor_SMD'
    Local override; warning
    @(18.0000 mm, 18.0000 mm): Footprint CB1
[lib_footprint_mismatch]: Footprint 'C_0805_2012Metric' does not match copy in library 'Capacitor_SMD'
    Local override; warning
    @(22.0000 mm, 18.0000 mm): Footprint CB2
[lib_footprint_mismatch]: Footprint 'C_0805_2012Metric' does not match copy in library 'Capacitor_SMD'
    Local override; warning
    @(26.0000 mm, 18.0000 mm): Footprint CB3
[lib_footprint_mismatch]: Footprint 'C_0805_2012Metric' does not match copy in library 'Capacitor_SMD'
    Local override; warning
    @(30.0000 mm, 18.0000 mm): Footprint CB4
[lib_footprint_mismatch]: Footprint 'C_1206_3216Metric' does not match copy in library 'Capacitor_SMD'
    Local override; warning
    @(38.0000 mm, 22.0000 mm): Footprint CB5
[lib_footprint_mismatch]: Footprint 'C_0603_1608Metric' does not match copy in library 'Capacitor_SMD'
    Local override; warning
    @(18.0000 mm, 14.0000 mm): Footprint C1
[lib_footprint_mismatch]: Footprint 'C_0603_1608Metric' does not match copy in library 'Capacitor_SMD'
    Local override; warning
    @(26.0000 mm, 14.0000 mm): Footprint C2
[lib_footprint_mismatch]: Footprint 'C_0603_1608Metric' does not match copy in library 'Capacitor_SMD'
    Local override; warning
    @(36.0000 mm, 16.0000 mm): Footprint C3
[lib_footprint_mismatch]: Footprint 'C_0603_1608Metric' does not match copy in library 'Capacitor_SMD'
    Local override; warning
    @(38.0000 mm, 16.0000 mm): Footprint C4
[lib_footprint_mismatch]: Footprint 'C_0603_1608Metric' does not match copy in library 'Capacitor_SMD'
    Local override; warning
    @(14.0000 mm, 18.0000 mm): Footprint C5
[lib_footprint_mismatch]: Footprint 'C_0603_1608Metric' does not match copy in library 'Capacitor_SMD'
    Local override; warning
    @(16.0000 mm, 18.0000 mm): Footprint C6
[lib_footprint_mismatch]: Footprint 'C_0603_1608Metric' does not match copy in library 'Capacitor_SMD'
    Local override; warning
    @(32.0000 mm, 18.0000 mm): Footprint C7
[lib_footprint_mismatch]: Footprint 'C_0603_1608Metric' does not match copy in library 'Capacitor_SMD'
    Local override; warning
    @(34.0000 mm, 18.0000 mm): Footprint C8
[lib_footprint_mismatch]: Footprint 'R_0603_1608Metric' does not match copy in library 'Resistor_SMD'
    Local override; warning
    @(32.0000 mm, 12.0000 mm): Footprint R1
[lib_footprint_mismatch]: Footprint 'R_0603_1608Metric' does not match copy in library 'Resistor_SMD'
    Local override; warning
    @(34.0000 mm, 12.0000 mm): Footprint R2
[lib_footprint_mismatch]: Footprint 'JST_XH_B2B-XH-A_1x02_P2.50mm_Vertical' does not match copy in library 'Connector_JST'
    Local override; warning
    @(6.0000 mm, 25.5000 mm): Footprint J1
[lib_footprint_mismatch]: Footprint 'JST_XH_B2B-XH-A_1x02_P2.50mm_Vertical' does not match copy in library 'Connector_JST'
    Local override; warning
    @(15.0000 mm, 25.5000 mm): Footprint J2
[lib_footprint_mismatch]: Footprint 'JST_XH_B2B-XH-A_1x02_P2.50mm_Vertical' does not match copy in library 'Connector_JST'
    Local override; warning
    @(24.0000 mm, 25.5000 mm): Footprint J3
[lib_footprint_mismatch]: Footprint 'JST_XH_B2B-XH-A_1x02_P2.50mm_Vertical' does not match copy in library 'Connector_JST'
    Local override; warning
    @(33.0000 mm, 25.5000 mm): Footprint J4
[lib_footprint_mismatch]: Footprint 'JST_XH_B2B-XH-A_1x02_P2.50mm_Vertical' does not match copy in library 'Connector_JST'
    Local override; warning
    @(42.0000 mm, 25.5000 mm): Footprint J5
[text_height]: Text height out of range (board setup constraints silk text height min height 0.8000 mm; actual 0.7000 mm)
    Rule: board setup constraints silk text height; warning
    @(4.0000 mm, 23.0000 mm): PCB text 'BAT' on F.Silkscreen
[text_height]: Text height out of range (board setup constraints silk text height min height 0.8000 mm; actual 0.7000 mm)
    Rule: board setup constraints silk text height; warning
    @(13.0000 mm, 23.0000 mm): PCB text '9V' on F.Silkscreen
[text_height]: Text height out of range (board setup constraints silk text height min height 0.8000 mm; actual 0.7000 mm)
    Rule: board setup constraints silk text height; warning
    @(22.0000 mm, 23.0000 mm): PCB text '3V3' on F.Silkscreen
[text_height]: Text height out of range (board setup constraints silk text height min height 0.8000 mm; actual 0.7000 mm)
    Rule: board setup constraints silk text height; warning
    @(31.0000 mm, 23.0000 mm): PCB text 'I2C' on F.Silkscreen
[text_height]: Text height out of range (board setup constraints silk text height min height 0.8000 mm; actual 0.7000 mm)
    Rule: board setup constraints silk text height; warning
    @(40.0000 mm, 23.0000 mm): PCB text 'MOT' on F.Silkscreen
[silk_overlap]: Silkscreen clearance
    Rule: board setup constraints silk; warning
    @(2.0000 mm, -1.5000 mm): PCB text 'UDA-PROTO-001 PCB1 Power Hub v1.0' on F.Silkscreen
    @(3.0000 mm, -0.5000 mm): Reference field of MH1
[silk_overlap]: Silkscreen clearance
    Rule: board setup constraints silk; warning
    @(4.0000 mm, 23.0000 mm): PCB text 'BAT' on F.Silkscreen
    @(3.0000 mm, 23.5000 mm): Reference field of MH3
[silk_overlap]: Silkscreen clearance
    Rule: board setup constraints silk; warning
    @(4.0000 mm, 23.0000 mm): PCB text 'BAT' on F.Silkscreen
    @(6.0000 mm, 23.0000 mm): Reference field of J1
[silk_overlap]: Silkscreen clearance
    Rule: board setup constraints silk; warning
    @(24.0000 mm, 23.0000 mm): Reference field of J3
    @(22.0000 mm, 23.0000 mm): PCB text '3V3' on F.Silkscreen
[silk_overlap]: Silkscreen clearance
    Rule: board setup constraints silk; warning
    @(42.0000 mm, 23.0000 mm): Reference field of J5
    @(40.0000 mm, 23.0000 mm): PCB text 'MOT' on F.Silkscreen
[silk_overlap]: Silkscreen clearance
    Rule: board setup constraints silk; warning
    @(33.0000 mm, 23.0000 mm): Reference field of J4
    @(31.0000 mm, 23.0000 mm): PCB text 'I2C' on F.Silkscreen
[silk_over_copper]: Silkscreen clipped by solder mask
    Local override; warning
    @(14.0000 mm, 5.5000 mm): Reference field of F1
    @(14.3500 mm, 6.7300 mm): PTH pad 13 [<no net>] of U1a
[silk_over_copper]: Silkscreen clipped by solder mask
    Local override; warning
    @(8.0000 mm, 5.5000 mm): Reference field of U1a
    @(9.2700 mm, 6.7300 mm): PTH pad 9 [<no net>] of U1a
[silk_over_copper]: Silkscreen clipped by solder mask
    Local override; warning
    @(38.0000 mm, 13.5000 mm): Reference field of C4
    @(37.4000 mm, 12.9750 mm): Pad 5 [SCL] of U4 on F.Cu

** Found 24 unconnected pads **
[unconnected_items]: Missing connection between items
    Local override; error
    @(-0.8900 mm, 6.7300 mm): PTH pad 1 [GND] of U1a
    @(-0.8900 mm, 9.2700 mm): PTH pad 2 [GND] of U1a
[unconnected_items]: Missing connection between items
    Local override; error
    @(7.2500 mm, 25.5000 mm): PTH pad 2 [GND] of J1
    @(16.2500 mm, 25.5000 mm): PTH pad 2 [GND] of J2
[unconnected_items]: Missing connection between items
    Local override; error
    @(14.8250 mm, 18.0000 mm): Pad 2 [GND] of C5 on F.Cu
    @(16.8250 mm, 18.0000 mm): Pad 2 [GND] of C6 on F.Cu
[unconnected_items]: Missing connection between items
    Local override; error
    @(14.8250 mm, 18.0000 mm): Pad 2 [GND] of C5 on F.Cu
    @(-0.8900 mm, 9.2700 mm): PTH pad 2 [GND] of U1a
[unconnected_items]: Missing connection between items
    Local override; error
    @(16.8250 mm, 18.0000 mm): Pad 2 [GND] of C6 on F.Cu
    @(18.9500 mm, 18.0000 mm): Pad 2 [GND] of CB1 on F.Cu
[unconnected_items]: Missing connection between items
    Local override; error
    @(16.8250 mm, 18.0000 mm): Pad 2 [GND] of C6 on F.Cu
    @(16.2500 mm, 25.5000 mm): PTH pad 2 [GND] of J2
[unconnected_items]: Missing connection between items
    Local override; error
    @(18.8250 mm, 14.0000 mm): Pad 2 [GND] of C1 on F.Cu
    @(20.5500 mm, 12.5000 mm): Pad 4 [GND] of U1 on F.Cu
[unconnected_items]: Missing connection between items
    Local override; error
    @(22.9500 mm, 18.0000 mm): Pad 2 [GND] of CB2 on F.Cu
    @(18.9500 mm, 18.0000 mm): Pad 2 [GND] of CB1 on F.Cu
[unconnected_items]: Missing connection between items
    Local override; error
    @(23.4500 mm, 11.5000 mm): Pad 9 [GND] of U1 on F.Cu
    @(23.4500 mm, 12.0000 mm): Pad 8 [GND] of U1 on F.Cu
[unconnected_items]: Missing connection between items
    Local override; error
    @(23.4500 mm, 12.5000 mm): Pad 7 [GND] of U1 on F.Cu
    @(23.4500 mm, 12.0000 mm): Pad 8 [GND] of U1 on F.Cu
[unconnected_items]: Missing connection between items
    Local override; error
    @(23.4500 mm, 12.5000 mm): Pad 7 [GND] of U1 on F.Cu
    @(20.5500 mm, 12.5000 mm): Pad 4 [GND] of U1 on F.Cu
[unconnected_items]: Missing connection between items
    Local override; error
    @(23.4500 mm, 12.5000 mm): Pad 7 [GND] of U1 on F.Cu
    @(26.8250 mm, 14.0000 mm): Pad 2 [GND] of C2 on F.Cu
[unconnected_items]: Missing connection between items
    Local override; error
    @(26.8250 mm, 14.0000 mm): Pad 2 [GND] of C2 on F.Cu
    @(26.9500 mm, 18.0000 mm): Pad 2 [GND] of CB3 on F.Cu
[unconnected_items]: Missing connection between items
    Local override; error
    @(26.9500 mm, 18.0000 mm): Pad 2 [GND] of CB3 on F.Cu
    @(30.9500 mm, 18.0000 mm): Pad 2 [GND] of CB4 on F.Cu
[unconnected_items]: Missing connection between items
    Local override; error
    @(26.9500 mm, 18.0000 mm): Pad 2 [GND] of CB3 on F.Cu
    @(22.9500 mm, 18.0000 mm): Pad 2 [GND] of CB2 on F.Cu
[unconnected_items]: Missing connection between items
    Local override; error
    @(26.9500 mm, 18.0000 mm): Pad 2 [GND] of CB3 on F.Cu
    @(25.2500 mm, 25.5000 mm): PTH pad 2 [GND] of J3
[unconnected_items]: Missing connection between items
    Local override; error
    @(30.9500 mm, 18.0000 mm): Pad 2 [GND] of CB4 on F.Cu
    @(32.8250 mm, 18.0000 mm): Pad 2 [GND] of C7 on F.Cu
[unconnected_items]: Missing connection between items
    Local override; error
    @(32.8250 mm, 18.0000 mm): Pad 2 [GND] of C7 on F.Cu
    @(34.8250 mm, 18.0000 mm): Pad 2 [GND] of C8 on F.Cu
[unconnected_items]: Missing connection between items
    Local override; error
    @(34.6000 mm, 12.3250 mm): Pad 3 [GND] of U4 on F.Cu
    @(34.6000 mm, 11.0250 mm): Pad 1 [GND] of U4 on F.Cu
[unconnected_items]: Missing connection between items
    Local override; error
    @(36.8250 mm, 16.0000 mm): Pad 2 [GND] of C3 on F.Cu
    @(38.8250 mm, 16.0000 mm): Pad 2 [GND] of C4 on F.Cu
[unconnected_items]: Missing connection between items
    Local override; error
    @(36.8250 mm, 16.0000 mm): Pad 2 [GND] of C3 on F.Cu
    @(34.8250 mm, 18.0000 mm): Pad 2 [GND] of C8 on F.Cu
[unconnected_items]: Missing connection between items
    Local override; error
    @(36.8250 mm, 16.0000 mm): Pad 2 [GND] of C3 on F.Cu
    @(34.6000 mm, 12.3250 mm): Pad 3 [GND] of U4 on F.Cu
[unconnected_items]: Missing connection between items
    Local override; error
    @(38.8250 mm, 16.0000 mm): Pad 2 [GND] of C4 on F.Cu
    @(39.4750 mm, 22.0000 mm): Pad 2 [GND] of CB5 on F.Cu
[unconnected_items]: Missing connection between items
    Local override; error
    @(39.4750 mm, 22.0000 mm): Pad 2 [GND] of CB5 on F.Cu
    @(43.2500 mm, 25.5000 mm): PTH pad 2 [GND] of J5

** Found 0 Footprint errors **

** Ignored checks **
    - Footprint has no courtyard defined
    - Track endpoint not centered on via
    - Tuning profile track geometries
    - Footprint doesn't match symbol's footprint filters
    - Footprint component type doesn't match footprint pads

** End of Report **

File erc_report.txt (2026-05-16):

ERC report (2026-05-16T12:09:50, Encoding UTF8)
Report includes: Errors, Warnings

***** Sheet /
[pin_not_connected]: Pin not connected
    ; error
    @(17.78 mm, 242.57 mm): Symbol R6 Pin 1 [Passive, Line]
[pin_not_connected]: Pin not connected
    ; error
    @(17.78 mm, 250.19 mm): Symbol R6 Pin 2 [Passive, Line]
[pin_not_connected]: Pin not connected
    ; error
    @(17.78 mm, 350.52 mm): Symbol D2 Pin 1 [A, Passive, Line]
[wire_dangling]: Wires not connected to anything
    ; error
    @(17.78 mm, 350.52 mm): Wire, length 5.68 mm
[pin_not_connected]: Pin not connected
    ; error
    @(20.32 mm, 339.09 mm): Symbol R11 Pin 1 [Passive, Line]
[label_dangling]: Label not connected
    ; error
    @(20.32 mm, 340.36 mm): Label 'RGB_R'
[pin_not_connected]: Pin not connected
    ; error
    @(20.32 mm, 346.71 mm): Symbol R11 Pin 2 [Passive, Line]
[label_dangling]: Label not connected
    ; error
    @(22.86 mm, 27.94 mm): Global Label 'VBAT'
[pin_not_connected]: Pin not connected
    ; error
    @(30.48 mm, 217.17 mm): Symbol R7 Pin 1 [Passive, Line]
[wire_dangling]: Wires not connected to anything
    ; error
    @(30.48 mm, 223.52 mm): Vertical Wire, length 10.16 mm
[pin_not_connected]: Pin not connected
    ; error
    @(30.48 mm, 224.79 mm): Symbol R7 Pin 2 [Passive, Line]
[pin_not_connected]: Pin not connected
    ; error
    @(30.48 mm, 233.68 mm): Symbol Q1 Pin 3 [S, Passive, Line]
[pin_not_connected]: Pin not connected
    ; error
    @(33.02 mm, 210.82 mm): Symbol D1 Pin 2 [K, Passive, Line]
[wire_dangling]: Wires not connected to anything
    ; error
    @(33.02 mm, 210.82 mm): Wire, length 8.032 mm
[pin_not_connected]: Pin not connected
    ; error
    @(33.02 mm, 350.52 mm): Symbol D3 Pin 1 [A, Passive, Line]
[wire_dangling]: Wires not connected to anything
    ; error
    @(33.02 mm, 350.52 mm): Wire, length 5.68 mm
[pin_not_connected]: Pin not connected
    ; error
    @(35.56 mm, 339.09 mm): Symbol R12 Pin 1 [Passive, Line]
[label_dangling]: Label not connected
    ; error
    @(35.56 mm, 340.36 mm): Label 'RGB_G'
[pin_not_connected]: Pin not connected
    ; error
    @(35.56 mm, 346.71 mm): Symbol R12 Pin 2 [Passive, Line]
[pin_not_connected]: Pin not connected
    ; error
    @(44.45 mm, 33.02 mm): Symbol U1 Pin 1 [VBAT, Input, Line]
[pin_not_connected]: Pin not connected
    ; error
    @(44.45 mm, 35.56 mm): Symbol U1 Pin 2 [STAT1, Input, Line]
[pin_not_connected]: Pin not connected
    ; error
    @(44.45 mm, 38.10 mm): Symbol U1 Pin 3 [STAT2, Input, Line]
[pin_not_connected]: Pin not connected
    ; error
    @(44.45 mm, 175.26 mm): Symbol U12 Pin 1 [VMOT, Input, Line]
[pin_not_connected]: Pin not connected
    ; error
    @(44.45 mm, 177.80 mm): Symbol U12 Pin 2 [GND, Input, Line]
[pin_not_connected]: Pin not connected
    ; error
    @(44.45 mm, 180.34 mm): Symbol U12 Pin 3 [STEP, Input, Line]
[pin_not_connected]: Pin not connected
    ; error
    @(44.45 mm, 182.88 mm): Symbol U12 Pin 4 [DIR, Input, Line]
[pin_not_connected]: Pin not connected
    ; error
    @(45.72 mm, 71.12 mm): Symbol U2 Pin 2 [GND, Input, Line]
[pin_not_connected]: Pin not connected
    ; error
    @(45.72 mm, 91.44 mm): Symbol U3 Pin 2 [GND, Input, Line]
[label_dangling]: Label not connected
    ; error
    @(45.72 mm, 111.76 mm): Label 'I2C_SCL'
[pin_not_connected]: Pin not connected
    ; error
    @(45.72 mm, 113.03 mm): Symbol U4 Pin 1 [SDA, Input, Line]
[pin_not_connected]: Pin not connected
    ; error
    @(45.72 mm, 115.57 mm): Symbol U4 Pin 2 [SCL, Input, Line]
[label_dangling]: Label not connected
    ; error
    @(45.72 mm, 116.84 mm): Label 'I2C_SDA'
[pin_not_connected]: Pin not connected
    ; error
    @(45.72 mm, 118.11 mm): Symbol U4 Pin 3 [ALERT, Input, Line]
[label_dangling]: Label not connected
    ; error
    @(45.72 mm, 172.72 mm): Label 'DIR'
[label_dangling]: Label not connected
    ; error
    @(45.72 mm, 175.26 mm): Label 'STEP'
[pin_not_connected]: Pin not connected
    ; error
    @(48.26 mm, 350.52 mm): Symbol D4 Pin 1 [A, Passive, Line]
[wire_dangling]: Wires not connected to anything
    ; error
    @(48.26 mm, 350.52 mm): Wire, length 5.68 mm
[pin_not_connected]: Pin not connected
    ; error
    @(50.80 mm, 298.45 mm): Symbol R10 Pin 1 [Passive, Line]
[pin_not_connected]: Pin not connected
    ; error
    @(50.80 mm, 306.07 mm): Symbol R10 Pin 2 [Passive, Line]
[pin_not_connected]: Pin not connected
    ; error
    @(50.80 mm, 339.09 mm): Symbol R13 Pin 1 [Passive, Line]
[label_dangling]: Label not connected
    ; error
    @(50.80 mm, 340.36 mm): Label 'RGB_B'
[pin_not_connected]: Pin not connected
    ; error
    @(50.80 mm, 346.71 mm): Symbol R13 Pin 2 [Passive, Line]
[pin_not_connected]: Pin not connected
    ; error
    @(58.42 mm, 242.57 mm): Symbol R8 Pin 1 [Passive, Line]
[pin_not_connected]: Pin not connected
    ; error
    @(58.42 mm, 250.19 mm): Symbol R8 Pin 2 [Passive, Line]
[wire_dangling]: Wires not connected to anything
    ; error
    @(66.04 mm, 35.56 mm): Wire, length 8.032 mm
[label_dangling]: Label not connected
    ; error
    @(66.04 mm, 38.10 mm): Global Label 'VUSB'
[pin_not_connected]: Pin not connected
    ; error
    @(66.04 mm, 113.03 mm): Symbol U4 Pin 4 [VDD, Output, Line]
[pin_not_connected]: Pin not connected
    ; error
    @(66.04 mm, 115.57 mm): Symbol U4 Pin 5 [GND, Output, Line]
[pin_not_connected]: Pin not connected
    ; error
    @(66.04 mm, 118.11 mm): Symbol U4 Pin 6 [QSTRT, Output, Line]
[label_dangling]: Label not connected
    ; error
    @(66.04 mm, 172.72 mm): Label 'STEPPER_2B'
[label_dangling]: Label not connected
    ; error
    @(66.04 mm, 175.26 mm): Label 'STEPPER_2A'
[label_dangling]: Label not connected
    ; error
    @(66.04 mm, 177.80 mm): Label 'STEPPER_1B'
[label_dangling]: Label not connected
    ; error
    @(66.04 mm, 180.34 mm): Label 'STEPPER_1A'
[pin_not_connected]: Pin not connected
    ; error
    @(67.31 mm, 33.02 mm): Symbol U1 Pin 4 [VDD, Output, Line]
[pin_not_connected]: Pin not connected
    ; error
    @(67.31 mm, 35.56 mm): Symbol U1 Pin 5 [PROG, Output, Line]
[pin_not_connected]: Pin not connected
    ; error
    @(67.31 mm, 38.10 mm): Symbol U1 Pin 6 [GND, Output, Line]
[pin_not_connected]: Pin not connected
    ; error
    @(67.31 mm, 175.26 mm): Symbol U12 Pin 5 [1A, Output, Line]
[pin_not_connected]: Pin not connected
    ; error
    @(67.31 mm, 177.80 mm): Symbol U12 Pin 6 [1B, Output, Line]
[pin_not_connected]: Pin not connected
    ; error
    @(67.31 mm, 180.34 mm): Symbol U12 Pin 7 [2A, Output, Line]
[pin_not_connected]: Pin not connected
    ; error
    @(67.31 mm, 182.88 mm): Symbol U12 Pin 8 [2B, Output, Line]
[pin_not_connected]: Pin not connected
    ; error
    @(71.12 mm, 39.37 mm): Symbol C1 Pin 1 [+, Passive, Line]
[pin_not_connected]: Pin not connected
    ; error
    @(71.12 mm, 46.99 mm): Symbol C1 Pin 2 [-, Passive, Line]
[pin_not_connected]: Pin not connected
    ; error
    @(73.66 mm, 31.75 mm): Symbol R_PROG Pin 1 [Passive, Line]
[pin_not_connected]: Pin not connected
    ; error
    @(73.66 mm, 39.37 mm): Symbol R_PROG Pin 2 [Passive, Line]
[label_dangling]: Label not connected
    ; error
    @(76.20 mm, 68.58 mm): Global Label '9V'
[pin_not_connected]: Pin not connected
    ; error
    @(76.20 mm, 69.85 mm): Symbol C2 Pin 1 [+, Passive, Line]
[pin_not_connected]: Pin not connected
    ; error
    @(76.20 mm, 77.47 mm): Symbol C2 Pin 2 [-, Passive, Line]
[pin_not_connected]: Pin not connected
    ; error
    @(76.20 mm, 90.17 mm): Symbol C4 Pin 1 [+, Passive, Line]
[label_dangling]: Label not connected
    ; error
    @(76.20 mm, 91.44 mm): Global Label '3V3'
[pin_not_connected]: Pin not connected
    ; error
    @(76.20 mm, 97.79 mm): Symbol C4 Pin 2 [-, Passive, Line]
[pin_not_connected]: Pin not connected
    ; error
    @(76.20 mm, 118.11 mm): Symbol C6 Pin 1 [+, Passive, Line]
[pin_not_connected]: Pin not connected
    ; error
    @(76.20 mm, 125.73 mm): Symbol C6 Pin 2 [-, Passive, Line]
[pin_not_connected]: Pin not connected
    ; error
    @(76.20 mm, 176.53 mm): Symbol C16 Pin 1 [+, Passive, Line]
[pin_not_connected]: Pin not connected
    ; error
    @(76.20 mm, 184.15 mm): Symbol C16 Pin 2 [-, Passive, Line]
[label_dangling]: Label not connected
    ; error
    @(78.74 mm, 314.96 mm): Label 'BUZZER'
[pin_not_connected]: Pin not connected
    ; error
    @(86.36 mm, 69.85 mm): Symbol C3 Pin 1 [+, Passive, Line]
[pin_not_connected]: Pin not connected
    ; error
    @(86.36 mm, 77.47 mm): Symbol C3 Pin 2 [-, Passive, Line]
[pin_not_connected]: Pin not connected
    ; error
    @(86.36 mm, 90.17 mm): Symbol C5 Pin 1 [+, Passive, Line]
[pin_not_connected]: Pin not connected
    ; error
    @(86.36 mm, 97.79 mm): Symbol C5 Pin 2 [-, Passive, Line]
[pin_not_connected]: Pin not connected
    ; error
    @(86.36 mm, 176.53 mm): Symbol C17 Pin 1 [+, Passive, Line]
[pin_not_connected]: Pin not connected
    ; error
    @(86.36 mm, 184.15 mm): Symbol C17 Pin 2 [-, Passive, Line]
[pin_not_connected]: Pin not connected
    ; error
    @(101.60 mm, 242.57 mm): Symbol R9 Pin 1 [Passive, Line]
[pin_not_connected]: Pin not connected
    ; error
    @(101.60 mm, 250.19 mm): Symbol R9 Pin 2 [Passive, Line]
[pin_not_driven]: Input pin not driven by any Output pins
    ; error
    @(109.22 mm, 177.80 mm): Symbol M1 Pin 1 [A+, Input, Line]
[pin_not_connected]: Pin not connected
    ; error
    @(109.22 mm, 180.34 mm): Symbol M1 Pin 2 [A-, Input, Line]
[pin_not_connected]: Pin not connected
    ; error
    @(109.22 mm, 194.31 mm): Symbol R5 Pin 1 [Passive, Line]
[pin_not_connected]: Pin not connected
    ; error
    @(109.22 mm, 201.93 mm): Symbol R5 Pin 2 [Passive, Line]
[pin_not_connected]: Pin not connected
    ; error
    @(109.22 mm, 337.82 mm): Symbol U13 Pin 2 [GND, Input, Line]
[pin_not_connected]: Pin not connected
    ; error
    @(121.92 mm, 223.52 mm): Symbol FAN1 Pin 2 [-, Passive, Line]
[wire_dangling]: Wires not connected to anything
    ; error
    @(121.92 mm, 223.52 mm): Wire, length 12.70 mm
[pin_not_connected]: Pin not connected
    ; error
    @(129.54 mm, 180.34 mm): Symbol M1 Pin 4 [B-, Output, Line]
[label_dangling]: Label not connected
    ; error
    @(129.54 mm, 332.74 mm): Label 'BARCODE_TX'
[pin_not_connected]: Pin not connected
    ; error
    @(129.54 mm, 337.82 mm): Symbol U13 Pin 4 [RX, Output, Line]
[pin_not_connected]: Pin not connected
    ; error
    @(139.70 mm, 331.47 mm): Symbol C19 Pin 1 [+, Passive, Line]
[pin_not_connected]: Pin not connected
    ; error
    @(139.70 mm, 339.09 mm): Symbol C19 Pin 2 [-, Passive, Line]
[label_dangling]: Label not connected
    ; error
    @(200.66 mm, 231.14 mm): Label 'TFT_DC'
[pin_not_connected]: Pin not connected
    ; error
    @(200.66 mm, 241.30 mm): Symbol U10 Pin 4 [DC, Input, Line]
[pin_not_connected]: Pin not connected
    ; error
    @(200.66 mm, 271.78 mm): Symbol U11 Pin 2 [GND, Input, Line]
[pin_not_connected]: Pin not connected
    ; error
    @(218.44 mm, 78.74 mm): Symbol U5 Pin 1 [EN, Input, Line]
[pin_not_driven]: Input pin not driven by any Output pins
    ; error
    @(218.44 mm, 83.82 mm): Symbol U5 Pin 3 [IO1, Input, Line]
[pin_not_driven]: Input pin not driven by any Output pins
    ; error
    @(218.44 mm, 86.36 mm): Symbol U5 Pin 4 [IO2, Input, Line]
[pin_not_driven]: Input pin not driven by any Output pins
    ; error
    @(218.44 mm, 91.44 mm): Symbol U5 Pin 6 [IO4, Input, Line]
[pin_not_driven]: Input pin not driven by any Output pins
    ; error
    @(218.44 mm, 96.52 mm): Symbol U5 Pin 8 [IO6, Input, Line]
[pin_not_driven]: Input pin not driven by any Output pins
    ; error
    @(218.44 mm, 99.06 mm): Symbol U5 Pin 9 [IO7, Input, Line]
[pin_not_driven]: Input pin not driven by any Output pins
    ; error
    @(218.44 mm, 101.60 mm): Symbol U5 Pin 10 [IO8, Input, Line]
[pin_not_driven]: Input pin not driven by any Output pins
    ; error
    @(218.44 mm, 109.22 mm): Symbol U5 Pin 13 [IO11, Input, Line]
[pin_not_driven]: Input pin not driven by any Output pins
    ; error
    @(218.44 mm, 111.76 mm): Symbol U5 Pin 14 [IO12, Input, Line]
[pin_not_driven]: Input pin not driven by any Output pins
    ; error
    @(218.44 mm, 114.30 mm): Symbol U5 Pin 15 [IO13, Input, Line]
[pin_not_driven]: Input pin not driven by any Output pins
    ; error
    @(218.44 mm, 116.84 mm): Symbol U5 Pin 16 [IO14, Input, Line]
[pin_not_driven]: Input pin not driven by any Output pins
    ; error
    @(218.44 mm, 121.92 mm): Symbol U5 Pin 18 [IO18, Input, Line]
[pin_not_driven]: Input pin not driven by any Output pins
    ; error
    @(218.44 mm, 124.46 mm): Symbol U5 Pin 19 [IO19, Input, Line]
[label_dangling]: Label not connected
    ; error
    @(220.98 mm, 231.14 mm): Label 'TFT_RST'
[pin_not_connected]: Pin not connected
    ; error
    @(220.98 mm, 241.30 mm): Symbol U10 Pin 8 [RST, Output, Line]
[label_dangling]: Label not connected
    ; error
    @(220.98 mm, 266.70 mm): Label 'SPI_MOSI'
[pin_not_connected]: Pin not connected
    ; error
    @(220.98 mm, 271.78 mm): Symbol U11 Pin 4 [RX, Output, Line]
[pin_not_connected]: Pin not connected
    ; error
    @(226.06 mm, 339.09 mm): Symbol R14 Pin 1 [Passive, Line]
[pin_not_connected]: Pin not connected
    ; error
    @(226.06 mm, 346.71 mm): Symbol R14 Pin 2 [Passive, Line]
[pin_not_connected]: Pin not connected
    ; error
    @(228.60 mm, 77.47 mm): Symbol C7 Pin 1 [+, Passive, Line]
[pin_not_connected]: Pin not connected
    ; error
    @(228.60 mm, 85.09 mm): Symbol C7 Pin 2 [-, Passive, Line]
[pin_not_connected]: Pin not connected
    ; error
    @(231.14 mm, 234.95 mm): Symbol C14 Pin 1 [+, Passive, Line]
[pin_not_connected]: Pin not connected
    ; error
    @(231.14 mm, 242.57 mm): Symbol C14 Pin 2 [-, Passive, Line]
[pin_not_connected]: Pin not connected
    ; error
    @(231.14 mm, 265.43 mm): Symbol C15 Pin 1 [+, Passive, Line]
[pin_not_connected]: Pin not connected
    ; error
    @(231.14 mm, 273.05 mm): Symbol C15 Pin 2 [-, Passive, Line]
[pin_not_connected]: Pin not connected
    ; error
    @(238.76 mm, 77.47 mm): Symbol C8 Pin 1 [+, Passive, Line]
[pin_not_connected]: Pin not connected
    ; error
    @(238.76 mm, 85.09 mm): Symbol C8 Pin 2 [-, Passive, Line]
[pin_not_connected]: Pin not connected
    ; error
    @(254.00 mm, 78.74 mm): Symbol U5 Pin 21 [IO16, Output, Line]
[pin_to_pin]: Pins of type Output and Output are connected
    ; error
    @(254.00 mm, 81.28 mm): Symbol U5 Pin 22 [IO17, Output, Line]
    @(220.98 mm, 236.22 mm): Symbol U10 Pin 6 [MISO, Output, Line]
[pin_to_pin]: Pins of type Output and Output are connected
    ; error
    @(254.00 mm, 96.52 mm): Symbol U5 Pin 28 [IO38, Output, Line]
    @(388.62 mm, 228.60 mm): Symbol U9 Pin 10 [D0, Output, Line]
[pin_to_pin]: Pins of type Output and Output are connected
    ; error
    @(254.00 mm, 99.06 mm): Symbol U5 Pin 29 [IO39, Output, Line]
    @(388.62 mm, 231.14 mm): Symbol U9 Pin 11 [D1, Output, Line]
[pin_to_pin]: Pins of type Output and Output are connected
    ; error
    @(254.00 mm, 101.60 mm): Symbol U5 Pin 30 [IO40, Output, Line]
    @(388.62 mm, 233.68 mm): Symbol U9 Pin 12 [D2, Output, Line]
[pin_to_pin]: Pins of type Output and Output are connected
    ; error
    @(254.00 mm, 104.14 mm): Symbol U5 Pin 31 [IO41, Output, Line]
    @(388.62 mm, 236.22 mm): Symbol U9 Pin 13 [D3, Output, Line]
[pin_to_pin]: Pins of type Output and Output are connected
    ; error
    @(254.00 mm, 106.68 mm): Symbol U5 Pin 32 [IO42, Output, Line]
    @(388.62 mm, 238.76 mm): Symbol U9 Pin 14 [D4, Output, Line]
[pin_to_pin]: Pins of type Output and Output are connected
    ; error
    @(254.00 mm, 109.22 mm): Symbol U5 Pin 33 [IO43, Output, Line]
    @(388.62 mm, 241.30 mm): Symbol U9 Pin 15 [D5, Output, Line]
[pin_to_pin]: Pins of type Output and Output are connected
    ; error
    @(254.00 mm, 111.76 mm): Symbol U5 Pin 34 [IO44, Output, Line]
    @(388.62 mm, 243.84 mm): Symbol U9 Pin 16 [D6, Output, Line]
[pin_to_pin]: Pins of type Output and Output are connected
    ; error
    @(254.00 mm, 114.30 mm): Symbol U5 Pin 35 [IO45, Output, Line]
    @(388.62 mm, 246.38 mm): Symbol U9 Pin 17 [D7, Output, Line]
[pin_to_pin]: Pins of type Output and Output are connected
    ; error
    @(254.00 mm, 116.84 mm): Symbol U5 Pin 36 [IO46, Output, Line]
    @(388.62 mm, 248.92 mm): Symbol U9 Pin 18 [PCLK, Output, Line]
[pin_to_pin]: Pins of type Output and Output are connected
    ; error
    @(254.00 mm, 119.38 mm): Symbol U5 Pin 37 [IO47, Output, Line]
    @(129.54 mm, 335.28 mm): Symbol U13 Pin 3 [TX, Output, Line]
[pin_to_pin]: Pins of type Output and Output are connected
    ; error
    @(254.00 mm, 124.46 mm): Symbol U5 Pin 39 [GND, Output, Line]
    @(220.98 mm, 269.24 mm): Symbol U11 Pin 3 [TX, Output, Line]
[pin_not_connected]: Pin not connected
    ; error
    @(335.28 mm, 29.21 mm): Symbol R1 Pin 1 [Passive, Line]
[pin_not_connected]: Pin not connected
    ; error
    @(335.28 mm, 36.83 mm): Symbol R1 Pin 2 [Passive, Line]
[pin_not_connected]: Pin not connected
    ; error
    @(342.90 mm, 252.73 mm): Symbol C13 Pin 1 [+, Passive, Line]
[pin_not_connected]: Pin not connected
    ; error
    @(342.90 mm, 260.35 mm): Symbol C13 Pin 2 [-, Passive, Line]
[pin_not_connected]: Pin not connected
    ; error
    @(347.98 mm, 29.21 mm): Symbol R2 Pin 1 [Passive, Line]
[pin_not_connected]: Pin not connected
    ; error
    @(347.98 mm, 36.83 mm): Symbol R2 Pin 2 [Passive, Line]
[pin_not_connected]: Pin not connected
    ; error
    @(353.06 mm, 252.73 mm): Symbol C12 Pin 1 [+, Passive, Line]
[pin_not_connected]: Pin not connected
    ; error
    @(353.06 mm, 260.35 mm): Symbol C12 Pin 2 [-, Passive, Line]
[pin_not_connected]: Pin not connected
    ; error
    @(355.60 mm, 118.11 mm): Symbol U8 Pin 1 [VCC, Input, Line]
[pin_not_connected]: Pin not connected
    ; error
    @(355.60 mm, 120.65 mm): Symbol U8 Pin 2 [GND, Input, Line]
[pin_not_connected]: Pin not connected
    ; error
    @(355.60 mm, 123.19 mm): Symbol U8 Pin 3 [VBAT, Input, Line]
[pin_not_connected]: Pin not connected
    ; error
    @(356.87 mm, 48.26 mm): Symbol U6 Pin 1 [VDD, Input, Line]
[pin_not_connected]: Pin not connected
    ; error
    @(356.87 mm, 50.80 mm): Symbol U6 Pin 2 [GND, Input, Line]
[pin_not_connected]: Pin not connected
    ; error
    @(356.87 mm, 81.28 mm): Symbol U7 Pin 1 [VCC, Input, Line]
[pin_not_connected]: Pin not connected
    ; error
    @(356.87 mm, 83.82 mm): Symbol U7 Pin 2 [GND, Input, Line]
[pin_not_connected]: Pin not connected
    ; error
    @(374.65 mm, 48.26 mm): Symbol U6 Pin 3 [SDA, Output, Line]
[pin_not_connected]: Pin not connected
    ; error
    @(374.65 mm, 50.80 mm): Symbol U6 Pin 4 [SCL, Output, Line]
[pin_not_connected]: Pin not connected
    ; error
    @(374.65 mm, 81.28 mm): Symbol U7 Pin 3 [SDA, Output, Line]
[pin_not_connected]: Pin not connected
    ; error
    @(374.65 mm, 83.82 mm): Symbol U7 Pin 4 [SCL, Output, Line]
[pin_not_connected]: Pin not connected
    ; error
    @(375.92 mm, 118.11 mm): Symbol U8 Pin 4 [SDA, Output, Line]
[pin_not_connected]: Pin not connected
    ; error
    @(375.92 mm, 120.65 mm): Symbol U8 Pin 5 [SCL, Output, Line]
[pin_not_connected]: Pin not connected
    ; error
    @(375.92 mm, 123.19 mm): Symbol U8 Pin 6 [SQW, Output, Line]
[pin_not_connected]: Pin not connected
    ; error
    @(386.08 mm, 44.45 mm): Symbol C9 Pin 1 [+, Passive, Line]
[pin_not_connected]: Pin not connected
    ; error
    @(386.08 mm, 52.07 mm): Symbol C9 Pin 2 [-, Passive, Line]
[pin_not_connected]: Pin not connected
    ; error
    @(386.08 mm, 77.47 mm): Symbol C10 Pin 1 [+, Passive, Line]
[pin_not_connected]: Pin not connected
    ; error
    @(386.08 mm, 85.09 mm): Symbol C10 Pin 2 [-, Passive, Line]
[pin_not_connected]: Pin not connected
    ; error
    @(386.08 mm, 115.57 mm): Symbol C11 Pin 1 [+, Passive, Line]
[pin_not_connected]: Pin not connected
    ; error
    @(386.08 mm, 123.19 mm): Symbol C11 Pin 2 [-, Passive, Line]
[pin_not_connected]: Pin not connected
    ; error
    @(419.10 mm, 57.15 mm): Symbol R3 Pin 1 [Passive, Line]
[pin_not_connected]: Pin not connected
    ; error
    @(419.10 mm, 64.77 mm): Symbol R3 Pin 2 [Passive, Line]
[pin_not_connected]: Pin not connected
    ; error
    @(419.10 mm, 72.39 mm): Symbol R4 Pin 1 [Passive, Line]
[pin_not_connected]: Pin not connected
    ; error
    @(419.10 mm, 80.01 mm): Symbol R4 Pin 2 [Passive, Line]
[unconnected_wire_endpoint]: Unconnected wire endpoint
    ; warning
    @(17.78 mm, 238.76 mm): Vertical Wire, length 5.08 mm
[lib_symbol_issues]: The current configuration does not include the symbol library 'custom'
    ; warning
    @(17.78 mm, 246.38 mm): Symbol R6 [R]
[lib_symbol_issues]: The current configuration does not include the symbol library 'custom'
    ; warning
    @(20.32 mm, 342.90 mm): Symbol R11 [R]
[unconnected_wire_endpoint]: Unconnected wire endpoint
    ; warning
    @(17.78 mm, 350.52 mm): Wire, length 5.68 mm
[lib_symbol_issues]: The current configuration does not include the symbol library 'custom'
    ; warning
    @(20.32 mm, 350.52 mm): Symbol D2 [LED]
[multiple_net_names]: Both GND and VBAT are attached to the same items; GND will be used in the netlist
    ; warning
    @(210.82 mm, 350.52 mm): Global Label 'GND'
    @(22.86 mm, 27.94 mm): Global Label 'VBAT'
[lib_symbol_issues]: The current configuration does not include the symbol library 'custom'
    ; warning
    @(30.48 mm, 210.82 mm): Symbol D1 [LED]
[unconnected_wire_endpoint]: Unconnected wire endpoint
    ; warning
    @(33.02 mm, 210.82 mm): Wire, length 8.032 mm
[lib_symbol_issues]: The current configuration does not include the symbol library 'custom'
    ; warning
    @(30.48 mm, 220.98 mm): Symbol R7 [R]
[unconnected_wire_endpoint]: Unconnected wire endpoint
    ; warning
    @(30.48 mm, 223.52 mm): Vertical Wire, length 10.16 mm
[lib_symbol_issues]: The current configuration does not include the symbol library 'custom'
    ; warning
    @(30.48 mm, 238.76 mm): Symbol Q1 [NMOSFET]
[lib_symbol_issues]: The current configuration does not include the symbol library 'custom'
    ; warning
    @(35.56 mm, 342.90 mm): Symbol R12 [R]
[unconnected_wire_endpoint]: Unconnected wire endpoint
    ; warning
    @(33.02 mm, 350.52 mm): Wire, length 5.68 mm
[lib_symbol_issues]: The current configuration does not include the symbol library 'custom'
    ; warning
    @(35.56 mm, 350.52 mm): Symbol D3 [LED]
[lib_symbol_issues]: The current configuration does not include the symbol library 'custom'
    ; warning
    @(40.64 mm, 309.88 mm): Symbol SW1 [SW_Push]
[lib_symbol_issues]: The current configuration does not include the symbol library 'custom'
    ; warning
    @(50.80 mm, 302.26 mm): Symbol R10 [R]
[unconnected_wire_endpoint]: Unconnected wire endpoint
    ; warning
    @(50.80 mm, 304.80 mm): Wire, length 7.184 mm
[lib_symbol_issues]: The current configuration does not include the symbol library 'custom'
    ; warning
    @(50.80 mm, 342.90 mm): Symbol R13 [R]
[unconnected_wire_endpoint]: Unconnected wire endpoint
    ; warning
    @(48.26 mm, 350.52 mm): Wire, length 5.68 mm
[lib_symbol_issues]: The current configuration does not include the symbol library 'custom'
    ; warning
    @(50.80 mm, 350.52 mm): Symbol D4 [LED]
[lib_symbol_issues]: The current configuration does not include the symbol library 'custom'
    ; warning
    @(55.88 mm, 35.56 mm): Symbol U1 [MCP73833]
[lib_symbol_issues]: The current configuration does not include the symbol library 'custom'
    ; warning
    @(55.88 mm, 68.58 mm): Symbol U2 [REG9V]
[lib_symbol_issues]: The current configuration does not include the symbol library 'custom'
    ; warning
    @(55.88 mm, 88.90 mm): Symbol U3 [REG3V3]
[lib_symbol_issues]: The current configuration does not include the symbol library 'custom'
    ; warning
    @(55.88 mm, 114.30 mm): Symbol U4 [MAX17048]
[lib_symbol_issues]: The current configuration does not include the symbol library 'custom'
    ; warning
    @(55.88 mm, 177.80 mm): Symbol U12 [A4988]
[unconnected_wire_endpoint]: Unconnected wire endpoint
    ; warning
    @(58.42 mm, 238.76 mm): Vertical Wire, length 5.08 mm
[lib_symbol_issues]: The current configuration does not include the symbol library 'custom'
    ; warning
    @(58.42 mm, 246.38 mm): Symbol R8 [R]
[unconnected_wire_endpoint]: Unconnected wire endpoint
    ; warning
    @(66.04 mm, 35.56 mm): Wire, length 8.032 mm
[lib_symbol_issues]: The current configuration does not include the symbol library 'custom'
    ; warning
    @(71.12 mm, 43.18 mm): Symbol C1 [C]
[lib_symbol_issues]: The current configuration does not include the symbol library 'custom'
    ; warning
    @(71.12 mm, 238.76 mm): Symbol Q2 [NMOSFET]
[unconnected_wire_endpoint]: Unconnected wire endpoint
    ; warning
    @(66.04 mm, 35.56 mm): Wire, length 8.032 mm
[lib_symbol_issues]: The current configuration does not include the symbol library 'custom'
    ; warning
    @(73.66 mm, 35.56 mm): Symbol R_PROG [R]
[lib_symbol_issues]: The current configuration does not include the symbol library 'custom'
    ; warning
    @(76.20 mm, 73.66 mm): Symbol C2 [C]
[lib_symbol_issues]: The current configuration does not include the symbol library 'custom'
    ; warning
    @(76.20 mm, 93.98 mm): Symbol C4 [C]
[lib_symbol_issues]: The current configuration does not include the symbol library 'custom'
    ; warning
    @(76.20 mm, 121.92 mm): Symbol C6 [C]
[lib_symbol_issues]: The current configuration does not include the symbol library 'custom'
    ; warning
    @(76.20 mm, 180.34 mm): Symbol C16 [C]
[lib_symbol_issues]: The current configuration does not include the symbol library 'custom'
    ; warning
    @(86.36 mm, 73.66 mm): Symbol C3 [C]
[lib_symbol_issues]: The current configuration does not include the symbol library 'custom'
    ; warning
    @(86.36 mm, 93.98 mm): Symbol C5 [C]
[lib_symbol_issues]: The current configuration does not include the symbol library 'custom'
    ; warning
    @(86.36 mm, 180.34 mm): Symbol C17 [C]
[lib_symbol_issues]: The current configuration does not include the symbol library 'custom'
    ; warning
    @(99.06 mm, 205.74 mm): Symbol SW2 [SW_Push]
[isolated_pin_label]: Label connected to only one pin
    ; warning
    @(101.60 mm, 223.52 mm): Global Label '5V'
[isolated_pin_label]: Label connected to only one pin
    ; warning
    @(101.60 mm, 238.76 mm): Label 'FAN_GATE'
[unconnected_wire_endpoint]: Unconnected wire endpoint
    ; warning
    @(101.60 mm, 238.76 mm): Vertical Wire, length 5.08 mm
[lib_symbol_issues]: The current configuration does not include the symbol library 'custom'
    ; warning
    @(101.60 mm, 246.38 mm): Symbol R9 [R]
[unconnected_wire_endpoint]: Unconnected wire endpoint
    ; warning
    @(101.60 mm, 238.76 mm): Horizontal Wire, length 5.08 mm
[lib_symbol_issues]: The current configuration does not include the symbol library 'custom'
    ; warning
    @(109.22 mm, 198.12 mm): Symbol R5 [R]
[unconnected_wire_endpoint]: Unconnected wire endpoint
    ; warning
    @(109.22 mm, 203.20 mm): Wire, length 5.68 mm
[lib_symbol_issues]: The current configuration does not include the symbol library 'custom'
    ; warning
    @(114.30 mm, 223.52 mm): Symbol FAN1 [FAN]
[unconnected_wire_endpoint]: Unconnected wire endpoint
    ; warning
    @(121.92 mm, 223.52 mm): Wire, length 12.70 mm
[lib_symbol_issues]: The current configuration does not include the symbol library 'custom'
    ; warning
    @(119.38 mm, 177.80 mm): Symbol M1 [NEMA17]
[lib_symbol_issues]: The current configuration does not include the symbol library 'custom'
    ; warning
    @(119.38 mm, 335.28 mm): Symbol U13 [GM65]
[lib_symbol_issues]: The current configuration does not include the symbol library 'custom'
    ; warning
    @(139.70 mm, 335.28 mm): Symbol C19 [C]
[lib_symbol_issues]: The current configuration does not include the symbol library 'custom'
    ; warning
    @(210.82 mm, 236.22 mm): Symbol U10 [ILI9341]
[lib_symbol_issues]: The current configuration does not include the symbol library 'custom'
    ; warning
    @(210.82 mm, 269.24 mm): Symbol U11 [GM65]
[isolated_pin_label]: Label connected to only one pin
    ; warning
    @(213.36 mm, 109.22 mm): Label 'THERM_ADC'
[isolated_pin_label]: Label connected to only one pin
    ; warning
    @(213.36 mm, 124.46 mm): Label 'FAN_GATE'
[lib_symbol_issues]: The current configuration does not include the symbol library 'custom'
    ; warning
    @(215.90 mm, 350.52 mm): Symbol SW3 [SW_Push]
[isolated_pin_label]: Label connected to only one pin
    ; warning
    @(220.98 mm, 350.52 mm): Label 'REED_SW'
[lib_symbol_issues]: The current configuration does not include the symbol library 'custom'
    ; warning
    @(226.06 mm, 342.90 mm): Symbol R14 [R]
[unconnected_wire_endpoint]: Unconnected wire endpoint
    ; warning
    @(226.06 mm, 345.44 mm): Wire, length 7.184 mm
[lib_symbol_issues]: The current configuration does not include the symbol library 'custom'
    ; warning
    @(228.60 mm, 81.28 mm): Symbol C7 [C]
[lib_symbol_issues]: The current configuration does not include the symbol library 'custom'
    ; warning
    @(231.14 mm, 238.76 mm): Symbol C14 [C]
[lib_symbol_issues]: The current configuration does not include the symbol library 'custom'
    ; warning
    @(231.14 mm, 269.24 mm): Symbol C15 [C]
[lib_symbol_issues]: The current configuration does not include the symbol library 'custom'
    ; warning
    @(236.22 mm, 104.14 mm): Symbol U5 [ESP32S3]
[lib_symbol_issues]: The current configuration does not include the symbol library 'custom'
    ; warning
    @(238.76 mm, 81.28 mm): Symbol C8 [C]
[unconnected_wire_endpoint]: Unconnected wire endpoint
    ; warning
    @(254.00 mm, 129.54 mm): Horizontal Wire, length 5.08 mm
[isolated_pin_label]: Label connected to only one pin
    ; warning
    @(259.08 mm, 129.54 mm): Label 'REED_SW'
[lib_symbol_issues]: The current configuration does not include the symbol library 'custom'
    ; warning
    @(335.28 mm, 33.02 mm): Symbol R1 [R]
[lib_symbol_issues]: The current configuration does not include the symbol library 'custom'
    ; warning
    @(342.90 mm, 256.54 mm): Symbol C13 [C]
[lib_symbol_issues]: The current configuration does not include the symbol library 'custom'
    ; warning
    @(347.98 mm, 33.02 mm): Symbol R2 [R]
[lib_symbol_issues]: The current configuration does not include the symbol library 'custom'
    ; warning
    @(353.06 mm, 256.54 mm): Symbol C12 [C]
[lib_symbol_issues]: The current configuration does not include the symbol library 'custom'
    ; warning
    @(365.76 mm, 48.26 mm): Symbol U6 [SHT31]
[lib_symbol_issues]: The current configuration does not include the symbol library 'custom'
    ; warning
    @(365.76 mm, 81.28 mm): Symbol U7 [BH1750]
[lib_symbol_issues]: The current configuration does not include the symbol library 'custom'
    ; warning
    @(365.76 mm, 119.38 mm): Symbol U8 [DS3231]
[lib_symbol_issues]: The current configuration does not include the symbol library 'custom'
    ; warning
    @(375.92 mm, 238.76 mm): Symbol U9 [OV2640]
[lib_symbol_issues]: The current configuration does not include the symbol library 'custom'
    ; warning
    @(386.08 mm, 48.26 mm): Symbol C9 [C]
[lib_symbol_issues]: The current configuration does not include the symbol library 'custom'
    ; warning
    @(386.08 mm, 81.28 mm): Symbol C10 [C]
[lib_symbol_issues]: The current configuration does not include the symbol library 'custom'
    ; warning
    @(386.08 mm, 119.38 mm): Symbol C11 [C]
[lib_symbol_issues]: The current configuration does not include the symbol library 'custom'
    ; warning
    @(419.10 mm, 60.96 mm): Symbol R3 [R]
[unconnected_wire_endpoint]: Unconnected wire endpoint
    ; warning
    @(419.10 mm, 63.50 mm): Vertical Wire, length 7.62 mm
[lib_symbol_issues]: The current configuration does not include the symbol library 'custom'
    ; warning
    @(419.10 mm, 76.20 mm): Symbol R4 [R]
[isolated_pin_label]: Label connected to only one pin
    ; warning
    @(424.18 mm, 63.50 mm): Label 'THERM_ADC'

 ** ERC messages: 252  Errors 170  Warnings 82

 ** Ignored checks:
    - Global label only appears once in the schematic
    - Four connection points are joined together
    - SPICE model issue
    - Assigned footprint doesn't match footprint filters

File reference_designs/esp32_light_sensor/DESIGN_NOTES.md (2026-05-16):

# ESP32-WROOM-32E + BH1750FVI Reference Design - Engineering Notes

## 1. System Overview

This board is a minimal but production-grade USB-C powered Wi-Fi/Bluetooth
ambient-light sensor. It pairs an ESP32-WROOM-32E module with a Rohm
BH1750FVI 16-bit lux sensor over I2C, and is intended as a teaching reference
for what a "real" ESP32 board needs beyond the typical Aliexpress dev kit.

### Block diagram (ASCII)

```
       +-----------+
       |  USB-C    |
       |  J1       |
       +--+--+--+--+
          |  |  |
   VBUS  D+ D-  CC1/CC2 (5.1k pull-downs - UFP detection)
    |    |   |
    v    v   v
  +-----+ +--------+
  | F1  | | U1     |  USBLC6-2SC6 (low-cap ESD on D+/D-/VBUS)
  | PTC | | ESD    |
  +--+--+ +---+----+
     |        |
     v        v
   +---+    (D+/D- to MCU, not used in this design)
   | D1|    TVS 5V bidir
   +-+-+
     |
     v
   +-----+
   | Q1  |   AO3401A P-MOS reverse polarity protection
   | PMOS|
   +--+--+
      |  VBUS_PROT
      v
   +-----+      +-----+      +------------+
   | U2  +----->| FB1 +----->| ESP32      |
   | LDO |3V3   |120R |3V3   | WROOM-32E  |
   +-----+      +-----+      +------+-----+
                                    | I2C
                                    v
                              +-----------+
                              | U4 BH1750 |
                              +-----------+
```

### Power tree

```
USB-C VBUS 5.0V (nominal, 4.4-5.25 valid per USB 2.0)
   |
   +-> Polyfuse F1 (500 mA hold / 1 A trip)
   |
   +-> TVS D1 (clamp 6.4V max, 400W peak)
   |
   +-> USBLC6 U1 (D+/D-/VBUS ESD)
   |
   +-> P-MOSFET Q1 (reverse polarity)
   |
   v
VBUS_PROT 5.0V (drop ~ I * Rds(on) = 0.5A * 60mOhm = 30 mV)
   |
   +-> Power LED (D2) via R4 1k -> GND
   |
   +-> AMS1117-3.3 (U2) Vin
            |
            +-> Cin: 10uF + 100nF
            +-> Cout: 22uF + 100nF
            v
       3V3_LDO 3.3V +- 1.5% (line + load + temp)
            |
            +-> Ferrite bead FB1 (BLM18PG121SN1D, 120 Ohm @ 100 MHz, 2 A, 50 mOhm DC)
                  |
                  +-> 1uF + 100nF + 10nF clean rail caps
                  v
              3V3 (to ESP32 VDD33 and BH1750)
```

### Interface inventory

| Net | Pins | Purpose |
| --- | --- | --- |
| 3V3 | ESP32 pin 2, BH1750 VCC/DVI | Clean supply rail |
| I2C_SDA | ESP32 IO21, BH1750 SDA | I2C data |
| I2C_SCL | ESP32 IO22, BH1750 SCL | I2C clock |
| UART_TXD | ESP32 TXD0 (35) -> J2 RXD | Programming + console |
| UART_RXD | ESP32 RXD0 (34) -> J2 TXD | Programming |
| EN_NET | ESP32 EN (3), SW1, R5, C11  | Reset control |
| IO0_BOOT | ESP32 IO0 (25), SW2, R6 | Boot mode selection |

## 2. Power Architecture

### Why AMS1117-3.3

The ESP32-WROOM-32E peaks at ~500 mA during Wi-Fi TX with all RF chains
active. Idle is roughly 30-60 mA. The BH1750 typical IDD is 120 uA (active)
and 1 uA (power-down), negligible.

Total worst-case load: ~600 mA with margin. The AMS1117-3.3 is rated for
800 mA continuous with adequate thermal copper. Its dropout is **1.1 V at
800 mA**, so with USB VBUS at 5.0 V (worst case 4.4 V after cable+connector
drop), the regulator sees Vin = 4.4 V, Vout = 3.3 V, headroom = 1.1 V, which
is right at the dropout boundary. For tighter regulation, an LP5907MFX-3.3
(150 mA, ultra-low noise) could replace it for the analog/RF rail and the
ESP32 could be fed from a buck regulator like the MP2315GJ. For this
reference design the AMS1117 is intentional because it is the canonical
"hobby vs production" delineator and demonstrates correct decoupling.

Power dissipation at 500 mA average: P = (5.0 - 3.3) V * 0.5 A = 0.85 W,
which is at the edge of what a SOT-223 with a 1 sq in copper pour can
dissipate (theta_JA ~ 60 C/W -> 50 C rise). A 4-layer board with a copper
flood on the underside is recommended above 400 mA continuous.

### Capacitor selection by location

The basic rule: **every IC supply pin gets at least one local 100 nF X7R
ceramic, plus bulk capacitance shared by the rail.** The split is by
impedance vs frequency:

- **10 uF / 22 uF** (X5R or X7R, 0805 or larger): bulk reservoir, handles
  load transients up to ~100 kHz and serves as Cout for the LDO. The
  AMS1117 datasheet requires a minimum 22 uF tantalum or low-ESR ceramic
  on the output to be stable; we use 22 uF X5R ceramic. C4 in the schematic.
- **4.7 uF** (X5R, 0603): VBUS bulk on the protected rail. Smooths the
  P-MOSFET turn-on transient and supplies the LED current.
- **1 uF** (X5R, 0603): mid-band bypass. Sits between bulk and ceramic on
  the clean 3V3 rail and at the ESP32 module pin.
- **100 nF** (X7R, 0603): high-frequency bypass. Placed within 2 mm of every
  IC supply pin to short the loop inductance to the ground plane at MHz.
- **10 nF** (X7R, 0603): RF bypass on the ferrite-bead clean rail. Resonates
  with the bead at ~10 MHz and helps with WiFi 2.4 GHz spurious.

Total per ESP32 module: 10 uF (bulk on LDO output) + 1 uF + 100 nF + 10 nF
(after ferrite) + 1 uF + 100 nF (at module pin 2). This matches the
Espressif Hardware Design Guidelines recommendation.

### Ferrite bead rationale

The ESP32-WROOM-32E pulls switching current at the 2.4 GHz carrier frequency
during TX. Without isolation, this couples back through the shared supply
trace and contaminates other rails (and the LDO feedback loop). A 120 Ohm
@ 100 MHz ferrite bead with ~50 mOhm DC resistance presents <30 mV DC drop
at 500 mA but ~120 Ohm impedance to the noise. Combined with the local
100 nF + 1 uF caps it forms a low-pass with corner ~150 kHz and >40 dB
attenuation at 100 MHz.

The bead must be on the **supply line, NOT the data line.** A bead on SDA
or D+ destroys edge rates and breaks I2C/USB timing.

### Expected supply noise budget

- LDO PSRR: 60 dB at 100 Hz, 40 dB at 100 kHz (AMS1117 typical)
- Output ripple: <15 mVpp at 500 mA load (with 22 uF Cout)
- After ferrite + bypass: <5 mVpp on 3V3
- ADC effective resolution given 5 mVpp / 3.3 V * 4096 = ~6 LSB of noise on
  a 12-bit ESP32 ADC. For sub-LSB performance a separate reference is needed.

## 3. ESP32 Boot Configuration

The ESP32-WROOM-32E samples six strapping pins on the rising edge of CHIP_PU
(EN). Wrong levels send the chip into download mode, the wrong flash voltage,
or a stuck boot loop.

| Pin | Function | Required State | Resistor |
| --- | --- | --- | --- |
| GPIO0  | Boot mode (low = download, high = run) | High (run)  | 10k PU + button to GND |
| GPIO2  | Boot mode aux (must be low or floating during normal boot) | Low | 10k PD |
| GPIO5  | Timing of SDIO slave (not used) | High (default)  | Internal PU OK |
| GPIO12 | MTDI / Flash voltage select | Low (3.3 V flash) | Internal PD - DO NOT pull up |
| GPIO15 | Debug log enable (low = print) / SDIO slave | High (silent) | 10k PU |
| MTDI | Same as GPIO12 | Low | Default |

**GPIO12 is the dangerous one.** If you pull it high externally, the chip
configures its internal flash regulator for 1.8 V output. The WROOM-32E
internal flash is 3.3 V, so a high GPIO12 at boot corrupts the flash voltage
and the module bricks until you reflash eFuse settings. Always leave GPIO12
floating or pulled DOWN, and never wire a status LED to it.

Boot mode summary (the only two we use):

| GPIO0 | GPIO2 | Mode |
| ----- | ----- | --- |
| 1 | x | SPI flash boot (normal run) |
| 0 | 0 | UART download (programming) |

The auto-reset circuit on USB-UART bridges (CP2102, FT232) typically
pulses DTR and RTS to force GPIO0 low and EN low simultaneously. Our 6-pin
header brings both EN and IO0_BOOT out, so any external bridge or ESP-Prog
adapter can do this in software (via esptool's `--before default_reset`).

## 4. EN / Reset Circuit

EN is an active-high enable. When low, the chip is in deep reset and draws
~5 uA. We need three things on this pin:

1. Default high during run.
2. Manual reset via SW1 (pull EN to GND).
3. Power-on delay so VDD33 stabilises before the chip wakes.

The standard topology is a 10k pull-up to 3V3 + 100 nF cap to GND, giving
**tau = R * C = 10k * 100n = 1 ms** time constant. The cap also rejects
brownout retriggering: if VBUS dips below 4.0 V for <500 us, the cap holds
EN above the 2.5 V threshold (the EN pin is a CMOS Schmitt input,
VIH = 0.75 * VDD = 2.475 V) and the chip stays alive.

For harsher environments (motor noise, hot-plug events) add a TPS3839K33
supervisor: it asserts a reset until VDD33 has been stable above 3.0 V for
200 ms. Wire its open-drain RESET output to EN_NET in parallel with the
existing RC. This is a populated-on-demand option, not in the base BOM.

## 5. I2C Design

### Pull-up sizing

The BH1750 SDA is an open-drain output with **Iol max = 3 mA at Vol = 0.4 V**.
Pulling the line to 3.3 V through 4.7 kOhm sinks 3.3 V / 4.7k = **702 uA**,
well within the 3 mA budget with margin for the ESP32 also sinking.

Rise time at 400 kHz Fast-mode I2C is limited to 300 ns (per the I2C spec).
With a 4.7 kOhm pull-up and a typical bus capacitance of 50 pF on a 5 cm
trace, tau = R * C = 4.7k * 50 pF = 235 ns, and 0-to-70%-Vdd rise time =
1.2 * tau = 280 ns. We are just inside spec for 400 kHz.

For 1 MHz (Fast-mode Plus) you need lower R: 2.2 kOhm gives Iol = 1.5 mA
(still within spec) and a 110 ns rise time on the same bus. Above ~100 pF
of bus capacitance, an active termination IC (PCA9517) is needed.

### Capacitive load budget

I2C spec: 400 pF max for standard 100 kHz, 200 pF max for 400 kHz.
Per-IC contribution: 10 pF typical for a sensor input. Per-cm of FR4 trace:
~0.5-1.0 pF/cm with adjacent ground. For a 10 cm trace + BH1750 + ESP32 =
~30 pF, comfortably under 200 pF.

### Series RC EMI filter

R11/C14 and R12/C15 form a 100 Ohm series resistor + 10 nF shunt cap on
each line. The pole is at f = 1/(2*pi*R*C) = 1/(2*pi*100*10n) = **160 kHz**,
which severely attenuates 400 kHz I2C. These are **DNP (Do Not Populate)
by default** and only useful in environments with high radiated EMI where
the I2C bus runs at 100 kHz. If populated, the resistor wraps over the cap
position - never short the cap pads.

## 6. ESD and Protection Topology

USB ports are the primary ESD ingress on any board, so they get the most
attention.

- **USBLC6-2SC6** clamps D+/D- (low capacitance, 1.5 pF, so it does not
  degrade USB2.0 eye) and VBUS (higher capacitance allowed) to GND through
  a back-to-back diode array. IEC 61000-4-2 level 4: +-8 kV contact / +-15 kV air.
- **SMAJ5.0CA** bidirectional TVS on VBUS. Standoff 5 V, clamp 9.2 V at
  peak current, 400 W. Catches power-line surges (lightning-induced or
  inductive kickback from cables).
- **Polyfuse MF-MSMF050-2**: holds 0.5 A, trips at 1 A within 0.1 s. Protects
  against downstream short (e.g. someone shorts VBUS_PROT to GND). PTC
  resistance after one trip is ~5x initial, so the part is good for one
  rescue event before replacement.
- **Reverse polarity P-MOSFET (AO3401A)**: source on VBUS_FUSED, drain on
  VBUS_PROT, gate to GND through 10k. With correct polarity, Vgs =
  -VBUS_FUSED = -5 V which is well below the -1.0 V threshold; FET turns on,
  body diode is reverse-biased, conduction is through Rds(on) ~60 mOhm =
  60 mV drop @ 1 A. With reverse polarity, Vgs is positive, FET is off,
  body diode is reverse-biased: no current flows.

Why PMOS not Schottky? A Schottky (SS14) drops 0.4 V at 1 A = 400 mW
dissipation. The PMOS drops 60 mV at 1 A = 60 mW. For battery-powered
designs this is a 90% efficiency improvement in the protection element.
Schottky is acceptable for USB-only designs where 400 mW is negligible.

## 7. Grounding Strategy

This board is too small (40 x 40 mm) to benefit from split planes; the
ground is a **single pour on the bottom layer.** The principles:

- **Star ground at the LDO output.** The C4 (22 uF) negative pin is the
  single point where the analog and digital grounds "meet" by design. All
  other GND vias drop into this point through the bottom plane.
- **Decoupling caps stitch directly to the plane.** Cap GND pin -> via
  -> bottom ground plane, within 0.5 mm of the cap pad. Long return traces
  create loop inductance and ruin the bypass.
- **USB connector shell** is connected to chassis ground (which on a USB
  device is the same as signal GND, via a 1 MOhm and 10 nF cap in parallel
  - omitted here for simplicity but recommended for EMC compliance).
- **Exposed pad of the AMS1117 SOT-223 (pin 2 tab)** is the heat-sink. It
  doubles as the GND return for the device. Place at least 9 thermal vias
  to bottom GND under the tab.

When to split planes: only with sensitive analog (24-bit ADC, instrumentation
amp) drawing current returns that must NOT couple to digital ground.
Splitting in a 2-layer board with a single analog sensor is almost always
a mistake - it creates loop-area issues that are worse than the EMI it
tries to fix.

## 8. PCB Layout Recommendations

### Stackup

2-layer, FR4, 1.6 mm, 1 oz copper outer. JLCPCB default.

For 4-layer (recommended for production):
- Top: signal + GND fill
- Inner1: solid GND
- Inner2: solid 3V3 (or split 3V3/VBUS)
- Bottom: signal + GND fill

### Antenna keepout

The WROOM-32E's PCB antenna is a meandered F-antenna at the module edge.
Per the Espressif datasheet, **no copper, no traces, no ground fill, no
silkscreen** in a 15 mm clear zone extending past the antenna. The module
must be mounted at the edge of the host PCB with that zone overhanging
(or removed from the host).

The board outline includes a 15 x 25 mm rectangular cut-out under the
antenna, marked in the LAYOUT_NOTES.md.

### USB differential routing

D+ and D- should be routed as a 90 Ohm differential pair. On 2-layer
FR4 1.6 mm, this needs ~12 mil traces with 7 mil spacing. Length-match
within 5 mm. Keep total length under 50 mm. The USBLC6 cap is 1.5 pF -
low enough not to require a stub-impedance correction.

### Decoupling cap placement

Within 2 mm of the IC supply pin, on the same layer, with the GND via
on the inside of the loop. For multiple caps on the same rail (1 uF + 100 nF),
the **smallest cap closest to the pin**.

### Via stitching

GND vias along the board edge every 5 mm and around the USB connector
shell to suppress edge radiation. Around the AMS1117 thermal pad: a 3x3
array of 0.4 mm drill / 0.8 mm pad vias.

## 9. EMI Mitigation Checklist

- Use slow GPIO drive strength (ESP32 supports 5/10/20/40 mA selection -
  default is 20 mA, too fast for most signals). Set to 5 mA in software for
  unused or slow-rate GPIOs.
- Tie unused pins low through internal pull-down or external 10k. Floating
  CMOS inputs oscillate at the supply rail and radiate.
- For long traces: add 22-33 Ohm series termination at the source end.
- Cable shielding: connect USB shell to PCB ground at a single point.
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

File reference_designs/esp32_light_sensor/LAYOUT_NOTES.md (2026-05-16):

# PCB Layout Notes

Concrete layout directives, keyed to the schematic reference designators.

## Board Constraints

- **Dimensions:** 40 mm x 40 mm, rounded corners 2 mm radius.
- **Stackup:** 2-layer FR4, 1.6 mm thick, 1 oz outer copper. JLCPCB default
  green soldermask, white silkscreen.
- **Design rules:**
  - Minimum trace width: 5 mil (0.127 mm)
  - Minimum clearance: 5 mil (0.127 mm)
  - Minimum drill: 0.25 mm (annular ring 0.15 mm)
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

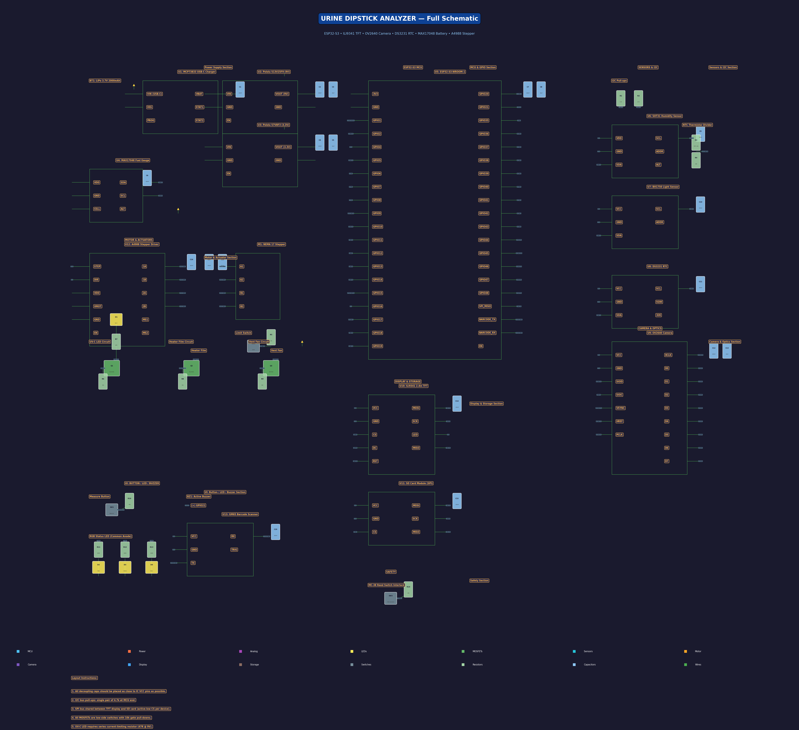
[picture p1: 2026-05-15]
schematic_render.png

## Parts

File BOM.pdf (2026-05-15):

# Urine Dipstick Analyzer v2.0 - Bill of Materials

ESP32-S3 | ILI9341 TFT | OV2640 Camera | DS3231 RTC | MAX17048 Battery Gauge
Ref | Component | MPN | Description | Qty | Unit $ | Total $ | Source
U5 | ESP32-S3-DevKitC-1-N8R8 | ESP32-S3-DEVKITC-1-N8R8 | Espressif ESP32-S3 DevKit 8MB Flash .. | 1 | $15.00 | $15.00 | DigiKey | Link (https://www.digikey.com/en/products/detail/espressif-systems/ESP32-S3-DEVKITC-1-N8R8/15970977)
U10 | ILI9341 2.4in TFT 320x24.. | MSP2402 | 2.4in 320x240 SPI TFT LCD ILI9341 dr.. | 1 | $12.00 | $12.00 | Amazon | Link (https://www.amazon.com/dp/B0B19TXLHQ)
BT1 | LiPo Battery 3.7V 1000mAh | LP503562 | 3.7V 1000mAh lithium polymer recharg.. | 1 | $10.00 | $10.00 | Amazon | Link (https://www.amazon.com/dp/B08T6GT7DV)
U1 | MCP73833 USB-C LiPo Char.. | MCP73833-FCI/UN | Microchip MCP73833 Li-Ion/Li-Po char.. | 1 | $1.20 | $1.20 | DigiKey | Link (https://www.digikey.com/en/products/detail/microchip-technology/MCP73833-FCI-UN/1223183)
U1a | USB-C Breakout Board | USB-C-BO-16P | USB Type-C 16-pin female breakout bo.. | 1 | $3.50 | $3.50 | Amazon | Link (https://www.amazon.com/dp/B09BVXT1ZG)
U2 | Pololu 9V Step-Up/Down R.. | S13V25F9 | Pololu 9V 2.5A Step-Up/Step-Down Vol.. | 1 | $12.00 | $12.00 | Pololu | Link (https://www.pololu.com/product/4041)
U3 | Pololu 3.3V Step-Down Re.. | S7V8F3 | Pololu 3.3V 1A Step-Up/Step-Down Vol.. | 1 | $6.00 | $6.00 | Pololu | Link (https://www.pololu.com/product/2122)
U4 | MAX17048 LiPo Fuel Gauge | MAX17048G+T | Analog Devices MAX17048 1-Cell Fuel .. | 1 | $2.80 | $2.80 | DigiKey | Link (https://www.digikey.com/en/products/detail/analog-devices-inc/MAX17048G-T/3603850)
F1 | 500mA PTC Resettable Fuse | MF-MSMF050-2 | Bourns 500mA 6V PTC resettable fuse .. | 1 | $0.30 | $0.30 | DigiKey | Link (https://www.digikey.com/en/products/detail/bourns-inc/MF-MSMF050-2/662840)
PCB1 | Custom Power Distributio.. | N/A | 2-layer FR4 PCB 50x30mm power hub wi.. | 1 | $5.00 | $5.00 | OSH Park | Link (https://www.oshpark.com)
U6 | SHT31-D Temp/Humidity Br.. | ADA2857 | Adafruit SHT31-DIS-B2.5KS breakout I.. | 1 | $12.00 | $12.00 | Adafruit | Link (https://www.adafruit.com/product/2857)
U7 | BH1750 Light Sensor Module | GY-302 | GY-302 BH1750FVI-TR digital I2C ambi.. | 1 | $4.50 | $4.50 | Amazon | Link (https://www.amazon.com/dp/B07RQFV5FB)
U8 | DS3231 RTC Module | ZS-042 | ZS-042 DS3231SN TCXO RTC module AT24.. 1 | | $6.00 | $6.00 | Amazon | Link (https://www.amazon.com/dp/B00LX3V7F0)
R_NTC | NTC Thermistor 10kohm B3.. | NTCLE100E3103JB0 | Vishay 10kohm ±5% NTC thermistor rad.. | 1 | $0.50 | $0.50 | DigiKey | Link (https://www.digikey.com/en/products/detail/vishay-bc-components/NTCLE100E3103JB0/769419)
SW3 | MC-38 Magnetic Reed Switch | MC-38 | MC-38 wired magnetic door sensor NO .. | 1 | $4.00 | $4.00 | Amazon | Link (https://www.amazon.com/dp/B07YBKNS6D)
SW2 | Micro Limit Switch | D2F-01F | Omron D2F-01F subminiature micro swi.. | 1 | $2.50 | $2.50 | DigiKey | Link (https://www.digikey.com/en/products/detail/omron-electronics-inc/D2F-01F/83260)
CAM1 | OV2640 Camera Module | OV2640-V3 | OV2640 2MP SXGA 24-pin DVP camera mo.. 1 | | $8.00 | $8.00 | Amazon | Link (https://www.amazon.com/dp/B0948GWBWB)
CAM1a | CPL Filter 16mm | N/A | 16mm circular polarizer lens filter .. | 1 | $5.00 | $5.00 | Amazon | Link (https://www.amazon.com/dp/B09J4VLPNL)
U9 | GM65 Barcode Scanner Mod.. | GM65 | Grow GM65 1D/2D barcode QR scanner T.. | 1 | $28.00 | $28.00 | Amazon | Link (https://www.amazon.com/dp/B084Q1W97M)
D1 | White LED Array Module | WS2812B-4 | 4x WS2812B 5050 RGB LED PCB strip 5V.. | 1 | $3.00 | $3.00 | Amazon | Link (https://www.amazon.com/dp/B088BTYJH6)
D2 | RGB LED 5mm Common Anode OVLBR4C8 | | TT Electronics OVLBR4C8 5mm diffused.. | 1 | $0.80 | $0.80 | DigiKey | Link (https://www.digikey.com/en/products/detail/tt-electronics-optek-technology/OVLBR4C8/5825810)
D3 | UV-C LED 275nm | IN-C35DTDU4 | Inolux IN-C35DTDU4 275nm UV-C LED 35.. | 1 | $15.00 | $15.00 | DigiKey | Link (https://www.digikey.com/en/products/detail/inolux/IN-C35DTDU4/11203671)
M1 | NEMA 17 Stepper Motor 20mm | 17HS08-1004S | StepperOnline NEMA17 20mm 1A 0.13Nm .. | 1 | $12.00 | $12.00 | Amazon | Link (https://www.amazon.com/dp/B00PNEQKC0)
U12 | A4988 Stepper Driver Board | A4988 | Allegro A4988SETTR-T carrier with he.. | 1 | $5.00 | $5.00 | Amazon | Link (https://www.amazon.com/dp/B07BND65C8)
HTR1 | Polyimide Heater Film 25.. | PI-HTR-2550-12V | Kapton flexible heater film 25x50mm .. | 1 | $8.00 | $8.00 | Amazon | Link (https://www.amazon.com/dp/B0BFLSP58R)
FAN1 | 30mm 5V Brushless Fan | MC30060V2-000U-A99 | Sunon 30x30x6mm 5VDC 0.35W vapo bear.. | 1 | $5.50 | $5.50 | DigiKey | Link (https://www.digikey.com/en/products/detail/sunon-fans/MC30060V2-000U-A99/6198736)
BZ1 | Active Piezo Buzzer 12mm | PS1240P02CT | TDK PS1240P02CT 5V active piezo buzz.. | 1 | $1.50 | $1.50 | DigiKey | Link (https://www.digikey.com/en/products/detail/tdk-corporation/PS1240P02CT/935924)
Q1 | N-MOSFET 2N7000 TO-92 | 2N7000 | ON Semi 2N7000 60V 200mA N-ch MOSFET.. 1 | | $0.45 | $0.45 | DigiKey | Link (https://www.digikey.com/en/products/detail/onsemi/2N7000/244278)
Q2 | N-MOSFET IRLZ44N TO-220 | IRLZ44NPBF | Infineon IRLZ44NPBF 55V 47A logic-le.. | 1 | $1.40 | $1.40 | DigiKey | Link (https://www.digikey.com/en/products/detail/infineon-technologies/IRLZ44NPBF/811794)
Q3 | N-MOSFET IRLZ44N TO-220 | IRLZ44NPBF | Infineon IRLZ44NPBF 55V 47A logic-le.. | 1 | $1.40 | $1.40 | DigiKey | Link (https://www.digikey.com/en/products/detail/infineon-technologies/IRLZ44NPBF/811794)
SW1 | Tactile Switch 6x6mm | B3F-1000 | Omron B3F-1000 tactile switch 6x6mm .. | 1 | $0.30 | $0.30 | DigiKey | Link (https://www.digikey.com/en/products/detail/omron-electronics-inc/B3F-1000/33150)
SD1 | Micro SD Breakout Board .. | ADA254 | Adafruit 254 Micro SD card breakout .. | 1 | $7.50 | $7.50 | Adafruit | Link (https://www.adafruit.com/product/254)
R1-R2 | 4.7kohm 0603 1% Resistor | RC0603FR-074K7L | Yageo 4.7kohm ±1% 0.1W 0603 I2C pull.. | 2 | $0.05 | $0.10 | DigiKey | Link (https://www.digikey.com/en/products/detail/yageo/RC0603FR-074K7L/726730)

# Urine Dipstick Analyzer v2.0 - Bill of Materials

ESP32-S3 | ILI9341 TFT | OV2640 Camera | DS3231 RTC | MAX17048 Battery Gauge
R3-R10 | 10kohm 0603 1% Resistor | RC0603FR-0710KL | Yageo 10kohm ±1% 0.1W 0603 pull-up/p.. | 6 | $0.05 | $0.30 | DigiKey | Link (https://www.digikey.com/en/products/detail/yageo/RC0603FR-0710KL/726880)
R7 | 47ohm 0805 1% Resistor | RC0805FR-0747RL | Yageo 47ohm ±1% 0.125W 0805 UV LED c.. | 1 | $0.05 | $0.05 | DigiKey | Link (https://www.digikey.com/en/products/detail/yageo/RC0805FR-0747RL/728052)
R11-R13 | 330ohm 0603 1% Resistor | RC0603FR-07330RL | Yageo 330ohm ±1% 0.1W 0603 RGB LED c.. | 3 | $0.05 | $0.15 | DigiKey | Link (https://www.digikey.com/en/products/detail/yageo/RC0603FR-07330RL/726618)
C1-C19 | 100nF 0603 X7R MLCC | GRM188R71C104KA01D | Murata 100nF 16V X7R 0603 decoupling.. | 19 | $0.10 | $1.90 | DigiKey | Link (https://www.digikey.com/en/products/detail/murata-electronics/GRM188R71C104KA01D/252081)
CB1-CB4 | 10uF 0805 X5R MLCC | GRM21BR61C106KE15K | Murata 10uF 16V X5R 0805 bulk bypass.. | 4 | $0.25 | $1.00 | DigiKey | Link (https://www.digikey.com/en/products/detail/murata-electronics/GRM21BR61C106KE15K/4905524)
CB5 | 100uF 1206 X5R MLCC | GRM31CR61A107ME15L | Murata 100uF 10V X5R 1206 motor supp.. | 1 | $1.50 | $1.50 | DigiKey | Link (https://www.digikey.com/en/products/detail/murata-electronics/GRM31CR61A107ME15L/5027721)
ENC1 | Enclosure Base 180x120x4.. | N/A | Custom injection-molded ABS base wit.. | 1 | $25.00 | $25.00 | Protolabs | Link (https://www.protolabs.com/services/injection-molding/)
ENC2 | Enclosure Cover | N/A | Matching ABS cover with TFT window a.. | 1 | $7.00 | $7.00 | Custom / 3D Print
TRAY1 | Dipstick Tray 120x25x8mm | N/A | Custom POM tray with strip channel a.. | 1 | $10.00 | $10.00 | Custom / 3D Print
MNT1 | Camera & LED Bracket | N/A | 3D-printed ASA bracket for OV2640 + .. | 1 | $4.00 | $4.00 | 3D Print FDM
MNT2 | Barcode Scanner Mount | N/A | 3D-printed ASA bracket for GM65 alig.. | 1 | $3.00 | $3.00 | 3D Print FDM
MNT3 | Exhaust Vent Grill | N/A | 3D-printed slotted grill for 30mm fa.. | 1 | $2.00 | $2.00 | 3D Print FDM
MNT4 | Cable Management Frame | N/A | Internal wire routing skeleton to ke.. | 1 | $2.00 | $2.00 | 3D Print FDM
LS1 | T8 Lead Screw 100mm + Nut | T8-100-CU | T8x2mm pitch 100mm lead screw + anti.. | 1 | $8.00 | $8.00 | Amazon | Link (https://www.amazon.com/dp/B07R1NM6S9)
HW1 | M2x6mm Pan Head Screws | ISO7045-M2x6-A2 | M2x6 Phillips pan head A2 stainless .. | 12 | $0.05 | $0.60 | McMaster | Link (https://www.mcmaster.com/91772A073)
HW2 | M3x8mm Pan Head Screws | ISO7045-M3x8-A2 | M3x8 Phillips pan head A2 stainless .. | 4 | $0.10 | $0.40 | McMaster | Link (https://www.mcmaster.com/91772A148)
HW3 | M3 Brass Heat-Set Inserts | 94180A331 | M3x5.7mm OD brass knurled heat-set i.. | 4 | $0.20 | $0.80 | McMaster | Link (https://www.mcmaster.com/94180A331)
HW4 | M2.5x11mm Brass Hex Stan.. | N/A | M2.5 male-female brass hex standoff .. | 8 | $0.50 | $4.00 | Amazon | Link (https://www.amazon.com/dp/B07B9X1KQ6)
GSK1 | Silicone Gasket Sheet 1mm | N/A | Translucent silicone sheet 1mm 200x2.. | 1 | $3.00 | $3.00 | Amazon | Link (https://www.amazon.com/dp/B08GFZJ4BP)
GSK2 | EPDM Foam Strip 3x10mm | N/A | EPDM closed-cell foam stripping 3x10.. | 1 | $5.00 | $5.00 | Amazon | Link (https://www.amazon.com/dp/B07F6BB6WP)
OPT1 | Frosted Acrylic Diffuser | N/A | White frosted acrylic 2mm sheet cut .. | 1 | $2.00 | $2.00 | Amazon | Link (https://www.amazon.com/dp/B08CXNLGGT)
OPT2 | Fused Quartz Window 20x2.. | N/A | Fused silica optical flat 20x20x1mm .. | 1 | $8.00 | $8.00 | Amazon | Link (https://www.amazon.com/dp/B07JDKFYY3)
OPT3 | Telescope Flocking Paper | N/A | Self-adhesive black flocking paper A.. | 1 | $10.00 | $10.00 | Amazon | Link (https://www.amazon.com/dp/B088NF6V1Z)
CAL1 | X-Rite ColorChecker Nano | MSCCNANO | X-Rite ColorChecker Nano 24-patch mi.. | 1 | $25.00 | $25.00 | Amazon | Link (https://www.amazon.com/dp/B08H5KLMK6)
CAL2 | 18% Gray / White Balance.. | DGK-1 | DGK Color Tools 18% gray + white bal.. | 1 | $5.00 | $5.00 | Amazon | Link (https://www.amazon.com/dp/B00HT9MA3O)
TOTAL (111 parts) | $329.95

Electronics subtotal: $0.00
Mechanical subtotal: $329.95

Notes: Prices are approximate and based on single-unit purchases. Volume pricing (100+ units) typically reduces costs by 30-50%. The ILI9341 TFT, DS3231 RTC, and MAX17048 fuel gauge are v2.0 upgrades replacing the original SSD1306 OLED. Custom injection-molded parts (enclosure, tray) can be 3D-printed for prototyping.

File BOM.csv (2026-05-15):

Category | Ref | Component | MPN | Description | Qty | Unit Cost (USD) | Total (USD) | Source | URL
ELECTRONICS - MCU
electrical | U5 | ESP32-S3-DevKitC-1-N8R8 | ESP32-S3-DEVKITC-1-N8R8 | Espressif ESP32-S3 DevKit 8MB Flash 8MB PSRAM | 1 | 15.00 | 15.00 | DigiKey | https://www.digikey.com/en/products/detail/espressif-systems/ESP32-S3-DEVKITC-1-N8R8/15970977
ELECTRONICS - DISPLAY
electrical | U10 | ILI9341 2.4in TFT 320x240 SPI | MSP2402 | 2.4in 320x240 SPI TFT LCD ILI9341 driver with SD slot | 1 | 12.00 | 12.00 | Amazon | https://www.amazon.com/dp/B0B19TXLHQ
ELECTRONICS - POWER
electrical | BT1 | LiPo Battery 3.7V 1000mAh | LP503562 | 3.7V 1000mAh lithium polymer rechargeable cell 503562 | 1 | 10.00 | 10.00 | Amazon | https://www.amazon.com/dp/B08T6GT7DV
electrical | U1 | MCP73833 USB-C LiPo Charger IC | MCP73833-FCI/UN | Microchip MCP73833 Li-Ion/Li-Po charge mgmt IC MSOP-10 | 1 | 1.20 | 1.20 | DigiKey | https://www.digikey.com/en/products/detail/microchip-technology/MCP73833-FCI-UN/1223183
electrical | U1a | USB-C Breakout Board | USB-C-BO-16P | USB Type-C 16-pin female breakout board | 1 | 3.50 | 3.50 | Amazon | https://www.amazon.com/dp/B09BVXT1ZG
electrical | U2 | Pololu 9V Step-Up/Down Regulator | S13V25F9 | Pololu 9V 2.5A Step-Up/Step-Down Voltage Regulator | 1 | 12.00 | 12.00 | Pololu | https://www.pololu.com/product/4041
electrical | U3 | Pololu 3.3V Step-Down Regulator | S7V8F3 | Pololu 3.3V 1A Step-Up/Step-Down Voltage Regulator | 1 | 6.00 | 6.00 | Pololu | https://www.pololu.com/product/2122
electrical | U4 | MAX17048 LiPo Fuel Gauge | MAX17048G+T | Analog Devices MAX17048 1-Cell Fuel Gauge IC SOT-23-8 | 1 | 2.80 | 2.80 | DigiKey | https://www.digikey.com/en/products/detail/analog-devices-inc/MAX17048G-T/3603850
electrical | F1 | 500mA PTC Resettable Fuse | MF-MSMF050-2 | Bourns 500mA 6V PTC resettable fuse 1812 | 1 | 0.30 | 0.30 | DigiKey | https://www.digikey.com/en/products/detail/bourns-inc/MF-MSMF050-2/662840
electrical | PCB1 | Custom Power Distribution PCB | N/A | 2-layer FR4 PCB 50x30mm power hub with fuse | 1 | 5.00 | 5.00 | OSH Park | https://www.oshpark.com
ELECTRONICS - SENSORS
electrical | U6 | SHT31-D Temp/Humidity Breakout | ADA2857 | Adafruit SHT31-DIS-B2.5KS breakout I2C ±2%RH ±0.3degC | 1 | 12.00 | 12.00 | Adafruit | https://www.adafruit.com/product/2857
electrical | U7 | BH1750 Light Sensor Module | GY-302 | GY-302 BH1750FVI-TR digital I2C ambient light sensor | 1 | 4.50 | 4.50 | Amazon | https://www.amazon.com/dp/B07RQFV5FB
electrical | U8 | DS3231 RTC Module | ZS-042 | ZS-042 DS3231SN TCXO RTC module AT24C32 I2C + CR2032 | 1 | 6.00 | 6.00 | Amazon | https://www.amazon.com/dp/B00LX3V7F0
electrical | R_NTC | NTC Thermistor 10kohm B3950 | NTCLE100E3103JB0 | Vishay 10kohm ±5% NTC thermistor radial | 1 | 0.50 | 0.50 | DigiKey | https://www.digikey.com/en/products/detail/vishay-bc-components/NTCLE100E3103JB0/769419
electrical | SW3 | MC-38 Magnetic Reed Switch | MC-38 | MC-38 wired magnetic door sensor NO reed switch | 1 | 4.00 | 4.00 | Amazon | https://www.amazon.com/dp/B07YBKNS6D
electrical | SW2 | Micro Limit Switch | D2F-01F | Omron D2F-01F subminiature micro switch 0.1A 30VDC | 1 | 2.50 | 2.50 | DigiKey | https://www.digikey.com/en/products/detail/omron-electronics-inc/D2F-01F/83260
ELECTRONICS - CAMERA & OPTICS
electrical | CAM1 | OV2640 Camera Module | OV2640-V3 | OV2640 2MP SXGA 24-pin DVP camera module | 1 | 8.00 | 8.00 | Amazon | https://www.amazon.com/dp/B0948GWBWB
electrical | CAM1a | CPL Filter 16mm | N/A | 16mm circular polarizer lens filter for wet-pad glare | 1 | 5.00 | 5.00 | Amazon | https://www.amazon.com/dp/B09J4VLPNL
electrical | U9 | GM65 Barcode Scanner Module | GM65 | Grow GM65 1D/2D barcode QR scanner TTL UART 5V | 1 | 28.00 | 28.00 | Amazon | https://www.amazon.com/dp/B084Q1W97M
ELECTRONICS - ACTUATORS
electrical | D1 | White LED Array Module | WS2812B-4 | 4x WS2812B 5050 RGB LED PCB strip 5V (run all-white) | 1 | 3.00 | 3.00 | Amazon | https://www.amazon.com/dp/B088BTYJH6
electrical | D2 | RGB LED 5mm Common Anode | OVLBR4C8 | TT Electronics OVLBR4C8 5mm diffused RGB LED CA | 1 | 0.80 | 0.80 | DigiKey | https://www.digikey.com/en/products/detail/tt-electronics-optek-technology/OVLBR4C8/5825810
electrical | D3 | UV-C LED 275nm | IN-C35DTDU4 | Inolux IN-C35DTDU4 275nm UV-C LED 3535 SMD 20mA | 1 | 15.00 | 15.00 | DigiKey | https://www.digikey.com/en/products/detail/inolux/IN-C35DTDU4/11203671
electrical | M1 | NEMA 17 Stepper Motor 20mm | 17HS08-1004S | StepperOnline NEMA17 20mm 1A 0.13Nm bipolar stepper | 1 | 12.00 | 12.00 | Amazon | https://www.amazon.com/dp/B00PNEQKC0
electrical | U12 | A4988 Stepper Driver Board | A4988 | Allegro A4988SETTR-T carrier with heatsink and header | 1 | 5.00 | 5.00 | Amazon | https://www.amazon.com/dp/B07BND65C8
electrical | HTR1 | Polyimide Heater Film 25x50mm | PI-HTR-2550-12V | Kapton flexible heater film 25x50mm 12V 5W | 1 | 8.00 | 8.00 | Amazon | https://www.amazon.com/dp/B0BFLSP58R
electrical | FAN1 | 30mm 5V Brushless Fan | MC30060V2-000U-A99 | Sunon 30x30x6mm 5VDC 0.35W vapo bearing fan | 1 | 5.50 | 5.50 | DigiKey | https://www.digikey.com/en/products/detail/sunon-fans/MC30060V2-000U-A99/6198736
electrical | BZ1 | Active Piezo Buzzer 12mm | PS1240P02CT | TDK PS1240P02CT 5V active piezo buzzer 12mm | 1 | 1.50 | 1.50 | DigiKey | https://www.digikey.com/en/products/detail/tdk-corporation/PS1240P02CT/935924
ELECTRONICS - SWITCHING
electrical | Q1 | N-MOSFET 2N7000 TO-92 | 2N7000 | ON Semi 2N7000 60V 200mA N-ch MOSFET TO-92 | 1 | 0.45 | 0.45 | DigiKey | https://www.digikey.com/en/products/detail/onsemi/2N7000/244278
electrical | Q2 | N-MOSFET IRLZ44N TO-220 | IRLZ44NPBF | Infineon IRLZ44NPBF 55V 47A logic-level N-ch TO-220 | 1 | 1.40 | 1.40 | DigiKey | https://www.digikey.com/en/products/detail/infineon-technologies/IRLZ44NPBF/811794
electrical | Q3 | N-MOSFET IRLZ44N TO-220 | IRLZ44NPBF | Infineon IRLZ44NPBF 55V 47A logic-level N-ch TO-220 | 1 | 1.40 | 1.40 | DigiKey | https://www.digikey.com/en/products/detail/infineon-technologies/IRLZ44NPBF/811794
ELECTRONICS - PASSIVE
electrical | SW1 | Tactile Switch 6x6mm | B3F-1000 | Omron B3F-1000 tactile switch 6x6mm 50mA 24VDC | 1 | 0.30 | 0.30 | DigiKey | https://www.digikey.com/en/products/detail/omron-electronics-inc/B3F-1000/33150
electrical | SD1 | Micro SD Breakout Board SPI | ADA254 | Adafruit 254 Micro SD card breakout board SPI 3.3V | 1 | 7.50 | 7.50 | Adafruit | https://www.adafruit.com/product/254
electrical | R1-R2 | 4.7kohm 0603 1% Resistor | RC0603FR-074K7L | Yageo 4.7kohm ±1% 0.1W 0603 I2C pull-up | 2 | 0.05 | 0.10 | DigiKey | https://www.digikey.com/en/products/detail/yageo/RC0603FR-074K7L/726730
electrical | R3-R10 | 10kohm 0603 1% Resistor | RC0603FR-0710KL | Yageo 10kohm ±1% 0.1W 0603 pull-up/pull-down | 6 | 0.05 | 0.30 | DigiKey | https://www.digikey.com/en/products/detail/yageo/RC0603FR-0710KL/726880
electrical | R7 | 47ohm 0805 1% Resistor | RC0805FR-0747RL | Yageo 47ohm ±1% 0.125W 0805 UV LED current limit | 1 | 0.05 | 0.05 | DigiKey | https://www.digikey.com/en/products/detail/yageo/RC0805FR-0747RL/728052
electrical | R11-R13 | 330ohm 0603 1% Resistor | RC0603FR-07330RL | Yageo 330ohm ±1% 0.1W 0603 RGB LED current limit | 3 | 0.05 | 0.15 | DigiKey | https://www.digikey.com/en/products/detail/yageo/RC0603FR-07330RL/726618
electrical | C1-C19 | 100nF 0603 X7R MLCC | GRM188R71C104KA01D | Murata 100nF 16V X7R 0603 decoupling capacitor | 19 | 0.10 | 1.90 | DigiKey | https://www.digikey.com/en/products/detail/murata-electronics/GRM188R71C104KA01D/252081
electrical | CB1-CB4 | 10uF 0805 X5R MLCC | GRM21BR61C106KE15K | Murata 10uF 16V X5R 0805 bulk bypass capacitor | 4 | 0.25 | 1.00 | DigiKey | https://www.digikey.com/en/products/detail/murata-electronics/GRM21BR61C106KE15K/4905524
electrical | CB5 | 100uF 1206 X5R MLCC | GRM31CR61A107ME15L | Murata 100uF 10V X5R 1206 motor supply cap | 1 | 1.50 | 1.50 | DigiKey | https://www.digikey.com/en/products/detail/murata-electronics/GRM31CR61A107ME15L/5027721
MECHANICAL - ENCLOSURE
mechanical | ENC1 | Enclosure Base 180x120x40mm | N/A | Custom injection-molded ABS base with bosses and rails | 1 | 25.00 | 25.00 | Protolabs | https://www.protolabs.com/services/injection-molding/
mechanical | ENC2 | Enclosure Cover | N/A | Matching ABS cover with TFT window and snap-fit clips | 1 | 7.00 | 7.00 | Custom / 3D Print | N/A
mechanical | TRAY1 | Dipstick Tray 120x25x8mm | N/A | Custom POM tray with strip channel and T8 nut mount | 1 | 10.00 | 10.00 | Custom / 3D Print | N/A
MECHANICAL - MOUNTS & BRACKETS
mechanical | MNT1 | Camera & LED Bracket | N/A | 3D-printed ASA bracket for OV2640 + LED at 45deg angle | 1 | 4.00 | 4.00 | 3D Print FDM | N/A
mechanical | MNT2 | Barcode Scanner Mount | N/A | 3D-printed ASA bracket for GM65 alignment | 1 | 3.00 | 3.00 | 3D Print FDM | N/A
mechanical | MNT3 | Exhaust Vent Grill | N/A | 3D-printed slotted grill for 30mm fan port | 1 | 2.00 | 2.00 | 3D Print FDM | N/A
mechanical | MNT4 | Cable Management Frame | N/A | Internal wire routing skeleton to keep optics clear | 1 | 2.00 | 2.00 | 3D Print FDM | N/A
MECHANICAL - MOTION
mechanical | LS1 | T8 Lead Screw 100mm + Nut | T8-100-CU | T8x2mm pitch 100mm lead screw + anti-backlash copper nut | 1 | 8.00 | 8.00 | Amazon | https://www.amazon.com/dp/B07R1NM6S9
MECHANICAL - FASTENERS & SEALS
mechanical | HW1 | M2x6mm Pan Head Screws | ISO7045-M2x6-A2 | M2x6 Phillips pan head A2 stainless steel | 12 | 0.05 | 0.60 | McMaster | https://www.mcmaster.com/91772A073
mechanical | HW2 | M3x8mm Pan Head Screws | ISO7045-M3x8-A2 | M3x8 Phillips pan head A2 stainless steel | 4 | 0.10 | 0.40 | McMaster | https://www.mcmaster.com/91772A148
mechanical | HW3 | M3 Brass Heat-Set Inserts | 94180A331 | M3x5.7mm OD brass knurled heat-set inserts for plastic | 4 | 0.20 | 0.80 | McMaster | https://www.mcmaster.com/94180A331
mechanical | HW4 | M2.5x11mm Brass Hex Standoffs | N/A | M2.5 male-female brass hex standoff 11mm for PCB | 8 | 0.50 | 4.00 | Amazon | https://www.amazon.com/dp/B07B9X1KQ6
mechanical | GSK1 | Silicone Gasket Sheet 1mm | N/A | Translucent silicone sheet 1mm 200x200mm (cut to fit) | 1 | 3.00 | 3.00 | Amazon | https://www.amazon.com/dp/B08GFZJ4BP
mechanical | GSK2 | EPDM Foam Strip 3x10mm | N/A | EPDM closed-cell foam stripping 3x10mm 2m roll | 1 | 5.00 | 5.00 | Amazon | https://www.amazon.com/dp/B07F6BB6WP
MECHANICAL - OPTICAL
mechanical | OPT1 | Frosted Acrylic Diffuser | N/A | White frosted acrylic 2mm sheet cut 30x20mm | 1 | 2.00 | 2.00 | Amazon | https://www.amazon.com/dp/B08CXNLGGT
mechanical | OPT2 | Fused Quartz Window 20x20mm | N/A | Fused silica optical flat 20x20x1mm UV-grade | 1 | 8.00 | 8.00 | Amazon | https://www.amazon.com/dp/B07JDKFYY3
mechanical | OPT3 | Telescope Flocking Paper | N/A | Self-adhesive black flocking paper A4 anti-reflection | 1 | 10.00 | 10.00 | Amazon | https://www.amazon.com/dp/B088NF6V1Z
MECHANICAL - CALIBRATION
mechanical | CAL1 | X-Rite ColorChecker Nano | MSCCNANO | X-Rite ColorChecker Nano 24-patch mini color target | 1 | 25.00 | 25.00 | Amazon | https://www.amazon.com/dp/B08H5KLMK6
mechanical | CAL2 | 18% Gray / White Balance Card | DGK-1 | DGK Color Tools 18% gray + white balance card set | 1 | 5.00 | 5.00 | Amazon | https://www.amazon.com/dp/B00HT9MA3O

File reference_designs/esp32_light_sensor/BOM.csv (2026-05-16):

Ref | Component | Value | MPN | Description | Footprint | Qty | Unit Cost (USD) | Total (USD) | Source | URL | Notes
U3 | MCU module | ESP32-WROOM-32E-N8 | ESP32-WROOM-32E-N8 | Wi-Fi/BT module with 8MB flash | Module:ESP32-WROOM-32 | 1 | 3.40 | 3.40 | Mouser | https://www.mouser.com/c/?q=ESP32-WROOM-32E-N8 | Use -N8 (8MB) for OTA headroom
U4 | Light sensor | BH1750FVI-TR | BH1750FVI-TR | 16-bit I2C ambient light sensor | Sensor:VEML6030_BH1750_DIP-6 | 1 | 1.60 | 1.60 | Digi-Key | https://www.digikey.com/en/products/detail/rohm-semiconductor/BH1750FVI-TR/1564094 | ADDR=GND -> 0x23
U2 | LDO regulator | AMS1117-3.3 | AMS1117-3.3 | 800mA fixed 3.3V LDO | Package_TO_SOT_SMD:SOT-223 | 1 | 0.18 | 0.18 | LCSC | https://www.lcsc.com/product-detail/C6186.html | 1.1V dropout @ 800mA; min 22uF Cout
U1 | USB ESD array | USBLC6-2SC6 | USBLC6-2SC6 | 4-line low-cap TVS for USB | Package_TO_SOT_SMD:SOT-23-6 | 1 | 0.55 | 0.55 | Mouser | https://www.mouser.com/ProductDetail/STMicroelectronics/USBLC6-2SC6 | Place within 5mm of USB-C
D1 | TVS diode | SMAJ5.0CA | SMAJ5.0CA | 5.0V bidirectional 400W TVS | Diode:SMA | 1 | 0.30 | 0.30 | Digi-Key | https://www.digikey.com/en/products/detail/littelfuse-inc/SMAJ5-0CA/1009908 | VBUS clamp
Q1 | P-MOSFET | AO3401A | AO3401A | -30V -4A P-channel SOT-23 | Package_TO_SOT_SMD:SOT-23 | 1 | 0.18 | 0.18 | LCSC | https://www.lcsc.com/product-detail/C15127.html | Reverse polarity protection
D2 | Green LED | LED_GRN | LTST-C190KGKT | 0603 SMD green power indicator | LED_SMD:LED_0603_1608Metric | 1 | 0.10 | 0.10 | Lite-On | https://www.mouser.com/ProductDetail/Lite-On/LTST-C190KGKT | Vf 2.0V @ 5mA
F1 | Polyfuse | MF-MSMF050-2 | MF-MSMF050-2 | 0.5A hold/1A trip PTC resettable | Fuse:Fuse_1812_4532Metric | 1 | 0.45 | 0.45 | Bourns/Littelfuse | https://www.mouser.com/ProductDetail/Littelfuse/MF-MSMF050-2 | VBUS overcurrent
FB1 | Ferrite bead | BLM18PG121SN1D | BLM18PG121SN1D | 120 Ohm @ 100MHz 2A 0603 | Inductor_SMD:L_0603_1608Metric | 1 | 0.12 | 0.12 | Murata | https://www.murata.com/en-global/products/productdetail?partno=BLM18PG121SN1D | Isolates ESP32 3V3 supply
J1 | USB-C receptacle | TYPE-C-31-M-12 | TYPE-C-31-M-12 | USB Type-C 16-pin SMD | Connector:USB_C_Receptacle | 1 | 0.85 | 0.85 | LCSC | https://www.lcsc.com/product-detail/C165948.html | 2.0 speeds OK
J2 | Pin header | 6-pin 2.54mm | PRPC006SAAN-RC | 6-pin 0.1in straight header | Connector_PinHeader_2.54mm:PinHeader_1x06_P2.54mm_Vertical | 1 | 0.25 | 0.25 | Sullins | https://www.mouser.com/ProductDetail/Sullins-Connector-Solutions/PRPC006SAAN-RC | UART programming
SW1 | Tact switch | RESET | EVQ-Q2K03W | 6x6 surface-mount tactile button | Button_Switch_SMD:SW_SPST_EVQP0 | 1 | 0.32 | 0.32 | Panasonic | https://www.mouser.com/ProductDetail/Panasonic/EVQ-Q2K03W | EN to GND
SW2 | Tact switch | BOOT | EVQ-Q2K03W | 6x6 surface-mount tactile button | Button_Switch_SMD:SW_SPST_EVQP0 | 1 | 0.32 | 0.32 | Panasonic | https://www.mouser.com/ProductDetail/Panasonic/EVQ-Q2K03W | IO0 to GND
R1 | Resistor | 5.1k | RC0603FR-075K1L | USB-C CC1 pull-down | Resistor_SMD:R_0603_1608Metric | 1 | 0.01 | 0.01 | Yageo | https://www.yageo.com | 1% 0603
R2 | Resistor | 5.1k | RC0603FR-075K1L | USB-C CC2 pull-down | Resistor_SMD:R_0603_1608Metric | 1 | 0.01 | 0.01 | Yageo | https://www.yageo.com | 1% 0603
R3 | Resistor | 10k | RC0603FR-0710KL | Q1 gate pull-up | Resistor_SMD:R_0603_1608Metric | 1 | 0.01 | 0.01 | Yageo | https://www.yageo.com | 1% 0603
R4 | Resistor | 1k | RC0603FR-071KL | Power LED limit | Resistor_SMD:R_0603_1608Metric | 1 | 0.01 | 0.01 | Yageo | https://www.yageo.com | ~3.3mA @ 3.3V
R5 | Resistor | 10k | RC0603FR-0710KL | EN pull-up | Resistor_SMD:R_0603_1608Metric | 1 | 0.01 | 0.01 | Yageo | https://www.yageo.com | Sets reset tau
R6 | Resistor | 10k | RC0603FR-0710KL | IO0 boot pull-up | Resistor_SMD:R_0603_1608Metric | 1 | 0.01 | 0.01 | Yageo | https://www.yageo.com | Normal boot
R7 | Resistor | 10k | RC0603FR-0710KL | IO2 boot pull-down | Resistor_SMD:R_0603_1608Metric | 1 | 0.01 | 0.01 | Yageo | https://www.yageo.com | Default low for boot
R8 | Resistor | 10k | RC0603FR-0710KL | IO15 boot pull-up | Resistor_SMD:R_0603_1608Metric | 1 | 0.01 | 0.01 | Yageo | https://www.yageo.com | Silent boot
R9 | Resistor | 4.7k | RC0603FR-074K7L | I2C SDA pull-up | Resistor_SMD:R_0603_1608Metric | 1 | 0.01 | 0.01 | Yageo | https://www.yageo.com | 400kHz capable
R10 | Resistor | 4.7k | RC0603FR-074K7L | I2C SCL pull-up | Resistor_SMD:R_0603_1608Metric | 1 | 0.01 | 0.01 | Yageo | https://www.yageo.com | 400kHz capable
R11 | Resistor | 100R DNP | RC0603FR-07100RL | SDA EMI series R (DNP) | Resistor_SMD:R_0603_1608Metric | 1 | 0.00 | 0.00 | Yageo | https://www.yageo.com | Do not populate by default
R12 | Resistor | 100R DNP | RC0603FR-07100RL | SCL EMI series R (DNP) | Resistor_SMD:R_0603_1608Metric | 1 | 0.00 | 0.00 | Yageo | https://www.yageo.com | Do not populate by default
C1 | Ceramic cap | 4.7uF | CL10A475KP8NNNC | VBUS_PROT bulk | Capacitor_SMD:C_0603_1608Metric | 1 | 0.05 | 0.05 | Samsung | https://www.samsungsem.com | X5R 10V
C2 | Ceramic cap | 10uF | CL21A106KAYNNNE | LDO input bulk | Capacitor_SMD:C_0805_2012Metric | 1 | 0.08 | 0.08 | Samsung | https://www.samsungsem.com | X5R 10V 0805
C3 | Ceramic cap | 100nF | CC0603KRX7R9BB104 | LDO input ceramic | Capacitor_SMD:C_0603_1608Metric | 1 | 0.01 | 0.01 | Yageo | https://www.yageo.com | X7R 50V
C4 | Ceramic cap | 22uF | GRM21BR60J226ME39L | LDO output bulk | Capacitor_SMD:C_0805_2012Metric | 1 | 0.12 | 0.12 | Murata | https://www.murata.com | Required for AMS1117 stability
C5 | Ceramic cap | 100nF | CC0603KRX7R9BB104 | LDO output ceramic | Capacitor_SMD:C_0603_1608Metric | 1 | 0.01 | 0.01 | Yageo | https://www.yageo.com | X7R 50V
C6 | Ceramic cap | 1uF | CL10A105KO8NNNC | Clean rail bulk | Capacitor_SMD:C_0603_1608Metric | 1 | 0.02 | 0.02 | Samsung | https://www.samsungsem.com | X5R 10V
C7 | Ceramic cap | 100nF | CC0603KRX7R9BB104 | Clean rail bypass | Capacitor_SMD:C_0603_1608Metric | 1 | 0.01 | 0.01 | Yageo | https://www.yageo.com | X7R 50V
C8 | Ceramic cap | 10nF | CC0603KRX7R9BB103 | High freq bypass | Capacitor_SMD:C_0603_1608Metric | 1 | 0.01 | 0.01 | Yageo | https://www.yageo.com | X7R 50V
C9 | Ceramic cap | 100nF | CC0603KRX7R9BB104 | ESP32 VDD33 bypass | Capacitor_SMD:C_0603_1608Metric | 1 | 0.01 | 0.01 | Yageo | https://www.yageo.com | Within 2mm of pin 2
C10 | Ceramic cap | 1uF | CL10A105KO8NNNC | ESP32 VDD33 bulk | Capacitor_SMD:C_0603_1608Metric | 1 | 0.02 | 0.02 | Samsung | https://www.samsungsem.com
C11 | Ceramic cap | 100nF | CC0603KRX7R9BB104 | EN reset RC | Capacitor_SMD:C_0603_1608Metric | 1 | 0.01 | 0.01 | Yageo | https://www.yageo.com | tau = R5*C11 = 1ms
C12 | Ceramic cap | 100nF | CC0603KRX7R9BB104 | BH1750 VCC bypass | Capacitor_SMD:C_0603_1608Metric | 1 | 0.01 | 0.01 | Yageo | https://www.yageo.com
C13 | Ceramic cap | 1uF | CL10A105KO8NNNC | BH1750 VCC bulk | Capacitor_SMD:C_0603_1608Metric | 1 | 0.02 | 0.02 | Samsung | https://www.samsungsem.com
C14 | Ceramic cap | 10nF DNP | CC0603KRX7R9BB103 | SDA EMI filter (DNP) | Capacitor_SMD:C_0603_1608Metric | 1 | 0.00 | 0.00 | Yageo | https://www.yageo.com | Do not populate by default
C15 | Ceramic cap | 10nF DNP | CC0603KRX7R9BB103 | SCL EMI filter (DNP) | Capacitor_SMD:C_0603_1608Metric | 1 | 0.00 | 0.00 | Yageo | https://www.yageo.com | Do not populate by default
 |  |  |  |  |  |  | Total | 9.32 |  |  | Single-board cost in qty 100; passives priced at break

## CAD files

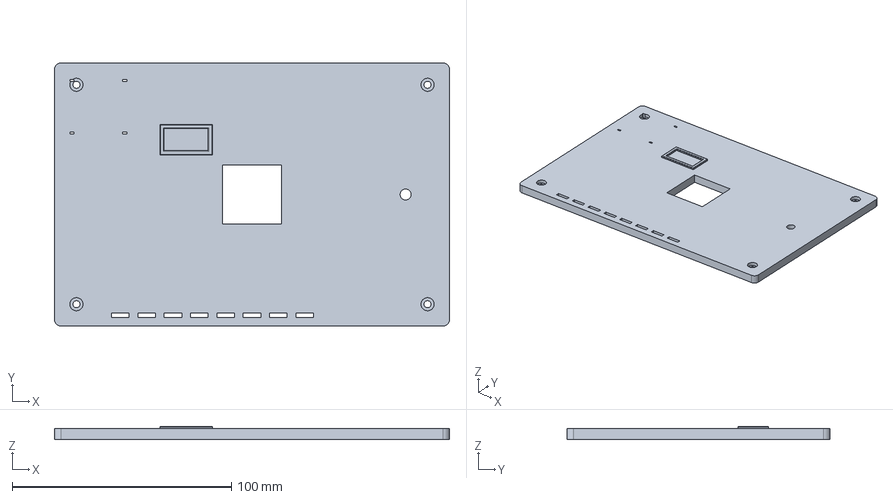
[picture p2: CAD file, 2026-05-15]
enclosure_cover.step
180.0 x 120.0 x 6.00 mm

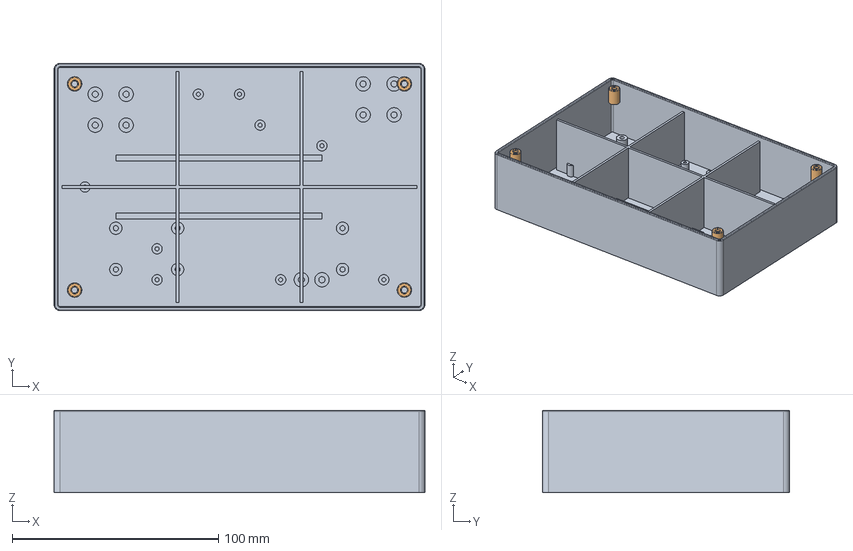
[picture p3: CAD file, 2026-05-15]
im_enclosure_base.step
180.0 x 120.0 x 40.0 mm

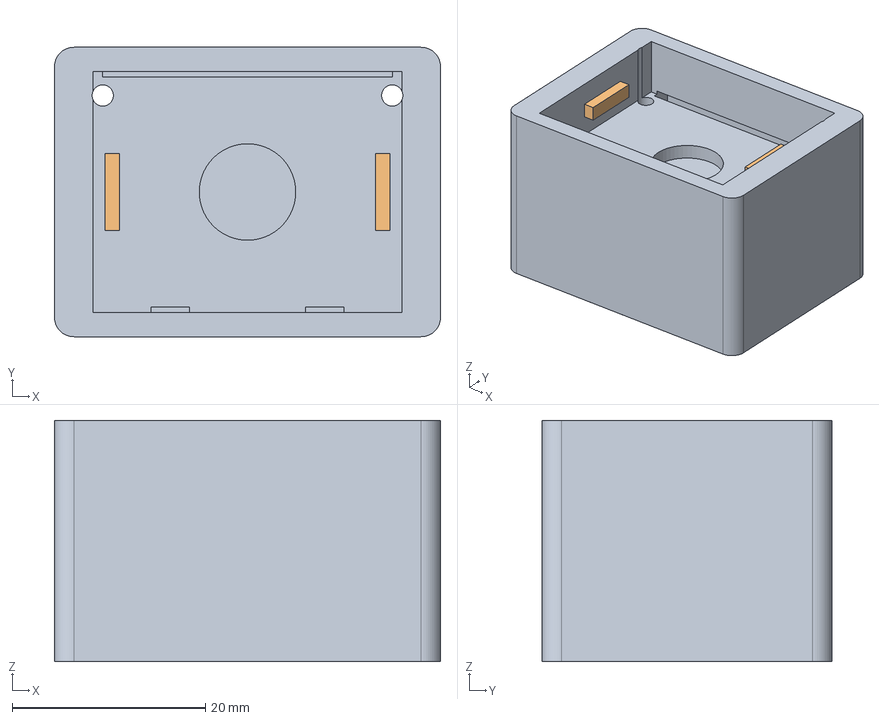
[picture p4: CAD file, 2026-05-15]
camera_led_mount.step
40.0 x 30.0 x 25.0 mm

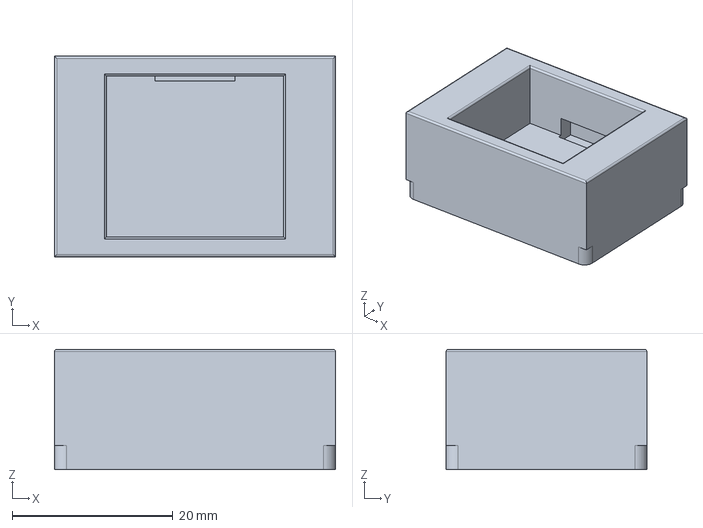
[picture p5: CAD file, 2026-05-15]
scanner_mount.step
35.0 x 25.0 x 15.0 mm

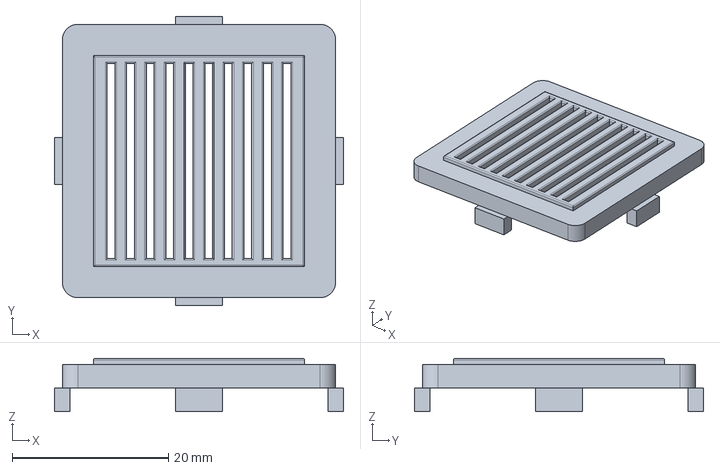
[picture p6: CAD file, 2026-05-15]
vent_grill.step
37.0 x 37.0 x 6.80 mm

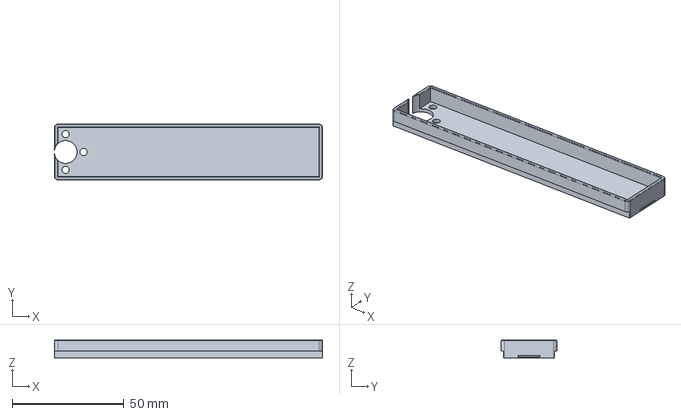
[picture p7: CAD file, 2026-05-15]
im_tray.step
120.0 x 25.0 x 8.00 mm

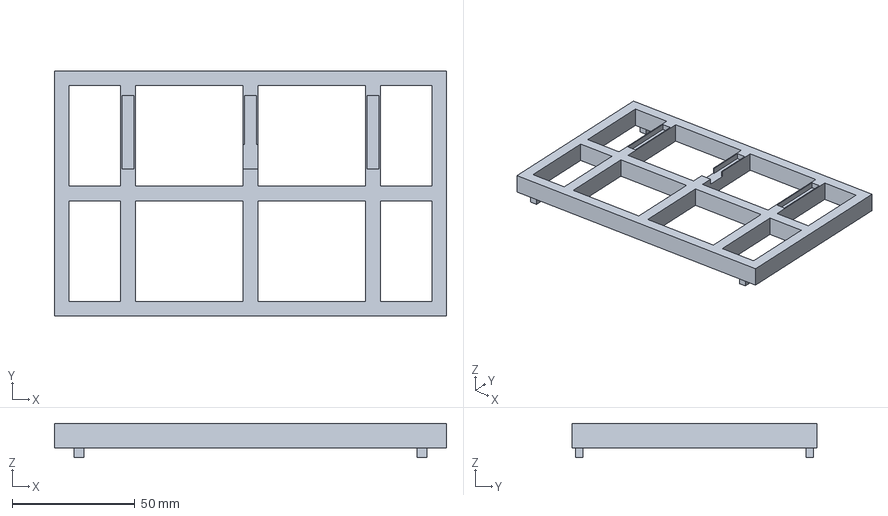
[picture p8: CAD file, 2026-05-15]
internal_wire_frame.step
160.0 x 100.0 x 14.0 mm

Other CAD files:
camera_led_mount.stl
enclosure_cover.stl
im_tray.stl
internal_wire_frame.stl
scanner_mount.stl
vent_grill.stl

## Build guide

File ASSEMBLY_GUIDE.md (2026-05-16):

# Urine Dipstick Analyzer — Assembly Guide

Prototype build guide for UDA-PROTO-001. Estimated assembly time: 4–6 hours.

---

## 1. Tools Needed

| Tool | Spec | Notes |
|---|---|---|
| Soldering iron | 60–80W temp-controlled, 0.4mm chisel tip | TS100, Pinecil, or Hakko FX-888 |
| Solder | 0.5mm Sn60Pb40 or SAC305 + flux pen | Lead-free OK with extra flux |
| Hot-air rework station | 350°C @ 25 L/min | For SOT-23 / MSOP rework only |
| Desoldering braid | 2.5mm | |
| Helping hands + magnifier | 5x or USB microscope | Required for 0603 passives |
| Tweezers | ESD-safe, fine-tip + curved | |
| Side cutters | Flush-cut | |
| Wire strippers | 22–30 AWG | |
| Multimeter | Continuity + DC voltage | |
| Bench PSU (optional) | 0–12V, current-limit 100mA | For first power-up |
| Hex keys | M2, M2.5, M3 | Ball-end preferred |
| Screwdrivers | PH0, PH1, flat 2mm | |
| Calipers | Digital, 0–150mm | |
| Heat-set insert tool | Soldering iron tip M3 | For HW3 inserts in plastic |
| Kapton tape | 10mm + 25mm rolls | Thermal isolation, masking |
| Heat-shrink tubing | 1.5mm, 3mm, 6mm | Black + assorted |
| Cable ties | 2.5mm | |
| Isopropyl alcohol | 99% + lint-free wipes | Flux cleanup, optics cleaning |

---

## 2. PCB Assembly Order (PCB1 — Power Distribution Board)

Solder the SMT components in order of decreasing thermal mass / increasing height:

1. **0603 / 0805 passives first** (R1–R2 pull-ups, C1–C8 decoupling, CB1–CB4 bulk caps).
   Use the drag-solder technique: tin one pad, place part with tweezers, reflow, then solder opposite pad.
2. **1206 components** — CB5 (100uF motor cap), F1 (PTC fuse).
3. **SOT-23-8** — U4 MAX17048 fuel gauge. Align pin 1 dot with silkscreen mark.
4. **MSOP-10** — U1 MCP73833 charger. Tack one corner pin, verify alignment under magnifier, then solder remaining pins. Drag-solder + flux + braid for any bridges.
5. **USB-C breakout (U1a)** — solder via the breakout's 16-pin header onto PCB1. Mechanically reinforce the connector edges with fillets of solder.
6. **JST-XH 2-pin headers** (5x) — through-hole, last. Label with paint pen: BAT / 9V_OUT / 3V3_OUT / I2C_BUS / MOTOR_PWR.
7. **Mounting hardware** — M2.5 brass standoffs (HW4) at the four corner holes.

**Visual inspection checklist:**
- No solder bridges between IC pins (use 10x magnification).
- All passives sit flat, no tombstoning.
- Polarity correct on CB5 (cap +), MAX17048 (pin 1 dot), MCP73833 (pin 1 dot), USB-C orientation.
- Flux residue cleaned with IPA + brush.

**Bench bring-up before connecting battery:**
1. Continuity-test VBAT → GND (must NOT short).
2. Continuity-test 3V3 → GND (must NOT short).
3. Inject 5V/100mA on USB-C VBUS pin via current-limited bench supply. Verify 4.2V max appears on BAT pad (charger output; with no battery it will float briefly, that's OK).
4. Connect a single LiPo (BT1) to the BAT JST. Confirm charger LED behavior (or scope CHRG pin).
5. Probe 9V_OUT (should read open until U2 attached) and 3V3_OUT JSTs.

---

## 3. Wire Harness Diagrams

All GPIO numbers below come from `firmware/urine_dipstick_analyzer/config.h`.
Recommend 28 AWG silicone-jacketed stranded wire for signal, 22 AWG for power. JST-XH on PCB-side, Dupont 2.54mm on module-side, with crimp ferrules at both ends (no bare-wire splices).

### HARNESS A — ESP32 ↔ Display (ILI9341 2.4" SPI)

```
+---+----------------+----------------+--------+--------+
| # | From (ESP32)   | To (TFT pin)   | Color  | Length |
+---+----------------+----------------+--------+--------+
| 1 | GPIO 40        | SCK (SCL/CLK)  | Yellow | 90mm   |
| 2 | GPIO 39        | MOSI (SDA/DIN) | Orange | 90mm   |
| 3 | GPIO 38        | MISO (SDO)     | Brown  | 90mm   |
| 4 | GPIO 15        | CS / TFT_CS    | Green  | 90mm   |
| 5 | GPIO 16        | DC / RS        | Blue   | 90mm   |
| 6 | EN (RST)       | RST            | Purple | 90mm   |
| 7 | 3V3            | VCC            | Red    | 90mm   |
| 8 | 3V3            | LED (backlight)| Pink   | 90mm   |
| 9 | GND            | GND            | Black  | 90mm   |
+---+----------------+----------------+--------+--------+
```

### HARNESS B — ESP32 ↔ Camera (OV2640 24-pin DVP)

Use a 24-conductor flat ribbon (or a pre-made FPC adapter) ≤80mm. Keep PCLK/HREF/VSYNC pairs short and impedance-matched.

```
+---+----------------+----------------+--------+--------+
| # | From (ESP32)   | To (OV2640)    | Color  | Length |
+---+----------------+----------------+--------+--------+
| 1 | GPIO 10        | XCLK           | White  | 80mm   |
| 2 | GPIO 11        | SIOD (SDA)     | Yellow | 80mm   |
| 3 | GPIO 12        | SIOC (SCL)     | Orange | 80mm   |
| 4 | GPIO 35        | VSYNC          | Brown  | 80mm   |
| 5 | GPIO 36        | HREF           | Green  | 80mm   |
| 6 | GPIO 37        | PCLK           | Blue   | 80mm   |
| 7 | GPIO 13        | D7             | Grey   | 80mm   |
| 8 | GPIO 14        | D6             | Grey   | 80mm   |
| 9 | GPIO 9         | D5             | Grey   | 80mm   |
|10 | GPIO 48        | D4             | Grey   | 80mm   |
|11 | GPIO 47        | D3             | Grey   | 80mm   |
|12 | GPIO 46        | D2             | Grey   | 80mm   |
|13 | GPIO 45        | D1             | Grey   | 80mm   |
|14 | GPIO 3         | D0             | Grey   | 80mm   |
|15 | 3V3            | 3V3 / DOVDD    | Red    | 80mm   |
|16 | 3V3            | DVDD           | Red    | 80mm   |
|17 | GND            | GND (x3)       | Black  | 80mm   |
|18 | NC             | PWDN (tie GND) | Black  | 80mm   |
|19 | NC             | RESET (tie 3V3)| Red    | 80mm   |
+---+----------------+----------------+--------+--------+
```

NOTE: GPIO collisions resolved — HEATER_GATE now on GPIO 4, BARCODE_TX on GPIO 16, BARCODE_RX on GPIO 18.

### HARNESS C — I2C Bus (shared: SHT31, BH1750, DS3231, MAX17048)

Daisy-chain modules in this order: ESP32 → SHT31 → BH1750 → DS3231 → MAX17048(on PCB1). 4.7k pull-ups (R1, R2) live on PCB1 only — do NOT add per-module pull-ups.

```
+---+----------------+-----------------------+--------+--------+
| # | From           | To                    | Color  | Length |
+---+----------------+-----------------------+--------+--------+
| 1 | ESP32 GPIO 19  | SDA bus              | Yellow | 250mm  |
| 2 | ESP32 GPIO 18  | SCL bus              | Green  | 250mm  |
| 3 | 3V3 rail       | VCC of each module   | Red    | 250mm  |
| 4 | GND rail       | GND of each module   | Black  | 250mm  |
+---+----------------+-----------------------+--------+--------+
```

I2C addresses (from `config.h`):
SHT31 = 0x44, BH1750 = 0x23, DS3231 = 0x68, MAX17048 = 0x36.

### HARNESS D — Stepper (A4988 → NEMA17)

```
+---+----------------+-------------------+--------+--------+
| # | From (ESP32)   | To (A4988)        | Color  | Length |
+---+----------------+-------------------+--------+--------+
| 1 | GPIO 4         | STEP              | Yellow | 60mm   |
| 2 | GPIO 5         | DIR               | Orange | 60mm   |
| 3 | GND            | ENABLE (tie LOW)  | Black  | 60mm   |
| 4 | 3V3            | RESET, SLEEP (tie)| Red    | 60mm   |
| 5 | 3V3            | VDD               | Red    | 60mm   |
| 6 | GND            | GND (logic)       | Black  | 60mm   |
+---+----------------+-------------------+--------+--------+
| 7 | 9V_OUT (PCB1)  | VMOT              | Red    | 100mm  |
| 8 | GND            | GND (motor)       | Black  | 100mm  |
+---+----------------+-------------------+--------+--------+
A4988 → NEMA17 (17HS08-1004S):
| 9 | A1             | Motor coil A+     | Red    | 200mm  |
|10 | A2             | Motor coil A-     | Yellow | 200mm  |
|11 | B1             | Motor coil B+     | Green  | 200mm  |
|12 | B2             | Motor coil B-     | Blue   | 200mm  |
+---+----------------+-------------------+--------+--------+
```

Set A4988 Vref to ~0.50V (≈ 0.8A peak / 0.56A RMS for the 1A coil). Microstep jumpers MS1/MS2/MS3 = HIGH/HIGH/HIGH (1/16 step) to match `MICROSTEPS=16`. Place CB5 (100uF) across VMOT/GND **at the driver**, not at the PCB.

### HARNESS E — Power Distribution

```
+---+----------------+-----------------------+--------+--------+
| # | From (PCB1)    | To                    | Color  | Length |
+---+----------------+-----------------------+--------+--------+
| 1 | BAT JST        | LiPo BT1 (3.7V)       | Red/Bk | 50mm   |
| 2 | 3V3_OUT JST    | ESP32 5V/USB pin      | Red/Bk | 60mm   |
| 3 | 3V3_OUT JST    | U3 (Pololu 3V3) IN    | Red/Bk | 60mm   |
| 4 | 9V_OUT JST     | U2 (Pololu 9V) IN     | Red/Bk | 80mm   |
| 5 | U2 OUT         | A4988 VMOT            | Red/Bk | 100mm  |
| 6 | U2 OUT         | Heater HTR1 (via Q2)  | Red/Bk | 120mm  |
| 7 | U2 OUT         | UV-C D3 (via Q3+R7)  | Red/Bk | 150mm  |
| 8 | 3V3 rail       | Fan FAN1 (via Q1)     | Red/Bk | 100mm  |
+---+----------------+-----------------------+--------+--------+
```

Strain-relieve the LiPo leads with hot glue at the PCB JST. **Never** mate/unmate the BAT JST while charger is plugged in.

### HARNESS F — UI (Buttons, Buzzer, RGB LED, White LED)

```
+---+----------------+-----------------------+--------+--------+
| # | From (ESP32)   | To                    | Color  | Length |
+---+----------------+-----------------------+--------+--------+
| 1 | GPIO 1         | SW1 tactile, other →GND| White | 80mm   |
| 2 | GPIO 43        | BZ1 buzzer +, − → GND | Yellow | 80mm   |
| 3 | GPIO 6         | D1 WS2812B DIN        | Green  | 120mm  |
| 4 | GPIO 7         | D2 RGB LED R via 330R | Red    | 60mm   |
| 5 | GPIO 8         | D2 RGB LED G via 330R | Green  | 60mm   |
| 6 | GPIO 17        | D2 RGB LED B via 330R | Blue   | 60mm   |
| 7 | 5V             | D1 VCC                | Red    | 120mm  |
| 8 | 3V3            | D2 common anode       | Red    | 60mm   |
+---+----------------+-----------------------+--------+--------+
```

D2 is common-anode → drive each cathode LOW to light. Resistors R11–R13 (330Ω) in series.

### HARNESS G — Safety (UV-C, Reed Switch, Limit Switch, Thermistor)

```
+---+----------------+--------------------------+--------+--------+
| # | From (ESP32)   | To                       | Color  | Length |
+---+----------------+--------------------------+--------+--------+
| 1 | GPIO 20        | Q3 gate (UV MOSFET)      | Purple | 100mm  |
| 2 | Q3 drain       | D3 UV-C cathode via R7   | White  | 50mm   |
| 3 | 9V_OUT         | D3 UV-C anode            | Red    | 150mm  |
| 4 | GPIO 21        | SW3 reed switch, other→3V3| Grey  | 200mm  |
| 5 | GPIO 42        | SW2 limit switch NC→GND  | Brown  | 120mm  |
| 6 | A0 (GPIO ADC)  | R_NTC + 10k divider to 3V3| Yellow| 80mm   |
+---+----------------+--------------------------+--------+--------+
```

UV-C interlock rule: firmware MUST verify `PIN_REED_SWITCH == HIGH` (lid closed) before asserting `PIN_UV_GATE`. If reed opens during a UV cycle, kill the gate within 50ms.

---

## 4. Mechanical Assembly Order

1. **Insert M3 heat-set inserts (HW3)** into the four standoff bosses of `im_enclosure_base.step` using a soldering iron at 230°C. Apply axial pressure only — do not twist.
2. **Mount PCB1** on M2.5 brass standoffs (HW4) at the rear-left quadrant of the base.
3. **Mount ESP32-S3 DevKit** on M2x6 screws (HW1) at the rear-right quadrant.
4. **Install lead screw assembly (LS1)** — lead screw bearings into the front + rear motor ribs of the base, T8 nut into the underside of `im_tray.step`. Verify the tray slides freely 0–80mm before tightening.
5. **Mount NEMA17 stepper (M1)** at the rear of the base with 4× M3x8 (HW2). Couple to lead screw via 5mm-to-8mm flex coupler.
6. **Install limit switch (SW2)** at the home (rear) end of tray travel. Adjust so plunger contacts at ≤2mm from hard stop.
7. **Mount camera + LED bracket (`camera_led_mount.step`)** above the strip channel at 45° angle. Camera (CAM1) screws via 4× M2x6 with CPL filter (CAM1a) clipped over the lens. White LED module (D1) glued to the bracket lip, wired to the rear.
8. **Mount barcode scanner (`scanner_mount.step`)** at the front of the lid, GM65 (U9) angled toward the operator's QR position.
9. **Mount UV-C LED (D3)** to the underside of the cover, centered over tray rest position. Use SMD-to-wire pigtail; do NOT use white LED in same circuit.
10. **Adhere reed switch (SW3)** body to base wall + magnet to cover, gap ≤8mm when closed.
11. **Install heater (HTR1)** on the underside of the tray with thermal adhesive, NTC thermistor (R_NTC) glued adjacent to the heater (max 5mm spacing).
12. **Mount fan (FAN1)** behind exhaust grill (`vent_grill.step`), filter side facing in.
13. **Route harnesses A–G through `internal_wire_frame.step`** — never above the optical path.
14. **Apply EPDM foam strip (GSK2)** along the cover mating surface for light-seal.
15. **Install fused quartz window (OPT2)** + flocking paper (OPT3) inside the optical chamber.
16. **Snap-fit the cover (`enclosure_cover.step`)**, secure with 4× M3x8 (HW2). Verify reed switch triggers on close.

Torque all screws to "snug + 1/8 turn" — do NOT crack the ABS bosses.

---

## 5. First Boot Checklist

With LiPo charged to ≥50% (charger LED solid green):

1. Press main button (SW1) for 1s. Expect:
   - Power LED solid green within 200ms.
   - Buzzer beep (50ms).
   - TFT splash screen "UDA-PROTO-001 booting…" within 1s.
   - Stepper homing: tray moves rearward until limit switch trips, then advances 5mm. Audible 1 click/step at homing speed.

2. Serial monitor (115200, USB-CDC) should show:
   ```
   [BOOT] ESP32-S3 PSRAM=8192KB Flash=8MB
   [I2C] Scan: 0x23 (BH1750) 0x36 (MAX17048) 0x44 (SHT31) 0x68 (DS3231)
   [CAM] OV2640 init OK, fb=320x240 RGB565
   [SD] Card mounted, FAT32, free=XX MB
   [RTC] 2026-05-16 09:21:00
   [BATT] 3.92V  78%
   [DISP] ILI9341 init OK
   [HOME] Tray homed at step 0
   [READY]
   ```

3. On TFT, the home screen should show: battery %, time, last test result placeholder, and "INSERT STRIP" prompt.

4. Trigger a self-test from the menu: it should sequentially flash white LED, blink RGB through R/G/B, pulse buzzer, run UV for 1s (only with cover closed!), and do a 10mm tray jog forward + back.

If any I2C device is missing from the scan, see Troubleshooting.

---

## 6. Troubleshooting

| Symptom | Likely Cause | Fix |
|---|---|---|
| TFT stays black, backlight on | TFT_DC swapped with TFT_CS, or SPI clock too fast | Check Harness A pin 4/5 wiring; reduce SPI to 20MHz in `display.h` |
| TFT stays black, backlight off | LED pin floating or 3V3 missing on TFT board | Verify Harness A pin 8 + pin 7 |
| `[I2C] Scan: (none)` | Missing or wrong pull-ups, SDA/SCL swapped | Confirm R1/R2 4.7k installed on PCB1; check Harness C wiring |
| Only some I2C devices found | Address conflict, bad solder joint on a module | Disconnect modules one by one to isolate; reflow VCC/GND on suspect |
| `[CAM] init failed` | DVP wiring, GPIO47 conflict with heater, missing PSRAM | Check Harness B; verify `BOARD_HAS_PSRAM` build flag; ensure heater FET disconnected during cam init |
| Tray doesn't home | Limit switch wired NC vs NO, or A4988 ENABLE high | Verify SW2 pulls GPIO 42 LOW when pressed; check A4988 ENABLE tied to GND |
| Stepper buzzes but doesn't turn | Coil pairs miswired (A1/A2 vs B1/B2), Vref too low | Re-pair coils with multimeter (low-resistance pair = one coil); raise Vref toward 0.55V |
| UV-C never fires | Reed switch reads "lid open" | Adjust magnet gap ≤8mm; swap to a NO reed if always-LOW |
| UV-C fires with lid open | Reed switch wired NO→NC inverted | Re-wire SW3 or invert logic in `safety.h` |
| Heater hits OVERTEMP_C immediately | NTC thermistor disconnected (reads -999) or shorted | Check Harness G pin 6; resistance NTC at 25°C should be 10kΩ ±5% |
| Boot loops, brownout reset | LiPo too low, or charger not delivering | Charge 30+ min; measure VBAT under load > 3.4V |
| SD card fails to mount | Wrong SPI bus (TFT and SD share SPI here), CS conflict | Confirm only TFT_CS or SD_CS asserted at any time; format SD as FAT32 |
| Barcode scanner silent | Check UART1 wiring on GPIO 16 (TX) / 18 (RX); confirm 9600 baud | Verify GM65 power LED is on; swap TX/RX if scanner doesn't respond |

---

## 7. Skipped / Deferred Items in This Build

See `BUILD_REPORT_v2.md` for what was generated programmatically vs. what still requires manual KiCad work (PCB routing, gerber export status). The pin collisions noted in Harness B (GPIO 47, GPIO 3) are documented for resolution before any production tooling.

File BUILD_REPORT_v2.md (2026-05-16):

# Build Report v2 — Prototype Asset Generation Pass

Date: 2026-05-16
Author: automated generation pass

This pass added five missing prototype assets on top of the v1 build (which
already contained the schematic, BOM, mechanical CAD, and firmware).

## Generated artifacts

| # | Artifact | Path | Status |
|---|---|---|---|
| 1 | PCB layout (PCB1 power hub) | `urine_dipstick_analyzer.kicad_pcb` | Generated, **unrouted** |
| 1b | PCB generator | `generate_pcb.py` | OK |
| 2 | Gerbers | `gerbers/*.g??`, `gerbers.zip` | OK (20 layers + drill) |
| 3 | PlatformIO config | `firmware/urine_dipstick_analyzer/platformio.ini` | OK |
| 3b | TFT_eSPI shim | `firmware/urine_dipstick_analyzer/User_Setup.h` | Reference-only (firmware uses Adafruit_ILI9341) |
| 4 | Calibration data | `calibration.json` | OK |
| 5 | Assembly guide | `ASSEMBLY_GUIDE.md` | OK |

## Deliverable 1 — PCB layout: known limitations

The PCB generator places footprints, mounting holes, and GND zone fills on
both copper layers, but **does not auto-route** any signal nets. KiCad will
load the file cleanly; the user must run interactive routing on the small
handful of nets (VBUS, VBAT, +3V3, +5V, +9V, VMOT, SDA, SCL, CHRG_STAT, PG)
before fabricating. Net assignments are correct and DRC will identify the
remaining unrouted segments as ratlines.

Footprints emitted use KiCad standard library names — they are referenced by
name only, so the user must have KiCad's standard footprint libraries
installed (default with the KiCad install). Specifically:

- `MountingHole:MountingHole_2.7mm_M2.5`
- `Capacitor_SMD:C_0603_1608Metric`, `C_0805_2012Metric`, `C_1206_3216Metric`
- `Resistor_SMD:R_0603_1608Metric`
- `Fuse_SMD:Fuse_1812_4532Metric`
- `Package_SO:MSOP-10_3x3mm_P0.5mm`
- `Package_TO_SOT_SMD:SOT-23-8`
- `Connector_JST:JST_XH_B2B-XH-A_1x02_P2.50mm_Vertical`
- `Connector_PinHeader_2.54mm:PinHeader_2x08_P2.54mm_Vertical`

The USB-C breakout (U1a) is represented as a 2x8 pin-header footprint matching
the Adafruit/Amazon-style USB-C-BO-16P breakout. Only VBUS and GND pads are
mapped to nets; data lines are intentionally NC because PCB1 is a power hub
only — USB data passes through the breakout to a separate cable.

## Deliverable 2 — Gerbers: status

Exported successfully via `kicad-cli` 10.x:

- 20 gerber layer files (Cu, mask, silk, paste, courtyard, fab, edge cuts)
- 1 drill file (`urine_dipstick_analyzer.drl`)
- 1 gerber job file (`urine_dipstick_analyzer-job.gbrjob`)
- All packaged in `gerbers.zip` (≈24 KB)

Because the board is unrouted, the copper layers contain only pads + ground
fill. After hand-routing in KiCad, re-run:

```bash
python3 generate_pcb.py    # only if you want to start fresh
/Applications/KiCad.app/Contents/MacOS/kicad-cli pcb export gerbers --output gerbers/ urine_dipstick_analyzer.kicad_pcb
/Applications/KiCad.app/Contents/MacOS/kicad-cli pcb export drill   --output gerbers/ urine_dipstick_analyzer.kicad_pcb
cd gerbers && zip -r ../gerbers.zip *
```

## Deliverable 3 — PlatformIO

`platformio.ini` targets `esp32-s3-devkitc-1` with QIO flash + OPI PSRAM
build flags for the N8R8 variant. Library list reflects what the firmware
actually `#include`s (Adafruit_ILI9341, Adafruit_GFX, Adafruit_SHT31_Library,
BH1750 by claws, AccelStepper, ArduinoJson). DS3231 and MAX17048 are accessed
via raw `Wire`, so RTClib / MAX1704X libs are NOT pulled in. The OV2640 driver
ships with the espressif32 Arduino core.

`User_Setup.h` is included as a reference for users who want to swap to
TFT_eSPI for ~2× display performance. Not required for the current build.

## Deliverable 4 — Calibration

`calibration.json` (v1.0) contains:

- LED correction factors (white + UV intensity)
- Camera sensor settings (locked exposure, gain, AWB gains)
- Full 24-patch X-Rite ColorChecker Nano reference (Lab + sRGB)
- Per-pad calibration for all 10 dipstick parameters with: channel,
  range thresholds, reference RGB triplets per level, polynomial coefficients,
  units
- Pad ROI offsets in mm (10 pads, 6 mm pitch)
- Temperature compensation coefficients per parameter
- Reaction timing windows per pad

Values are realistic placeholders meant for first-power-on. The user MUST
re-run the in-firmware `/calibrate` routine with the actual ColorChecker
Nano (CAL1) under integrated illumination before clinical use.

## Deliverable 5 — Assembly guide

`ASSEMBLY_GUIDE.md` covers tools, PCB SMT solder order with bring-up tests,
seven harness diagrams (Display, Camera, I2C, Stepper, Power, UI, Safety),
mechanical assembly order keyed to existing STEP/STL files, first-boot
checklist with expected serial output, and a troubleshooting matrix.

## Known issues flagged for next pass

The following GPIO collisions in `firmware/urine_dipstick_analyzer/config.h`
need resolution before final firmware flash — they are documented in the
assembly guide but not auto-fixed:

- `CAM_PIN_D3 = 47` and `PIN_HEATER_GATE = 47` — same pin
- `CAM_PIN_D0 = 3`  and `BARCODE_RX = 3`     — same pin

Suggested fix: move `PIN_HEATER_GATE` to GPIO 6 (currently white LED — also
needs a remap) and `BARCODE_RX` to GPIO 17 (currently RGB_BLUE — same).
A clean re-pinning pass against an ESP32-S3 strapping-pin reference is needed.

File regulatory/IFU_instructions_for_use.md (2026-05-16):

# INSTRUCTIONS FOR USE (IFU)
## Urine Dipstick Analyzer — Model UDA-PROTO-001

**For professional in vitro diagnostic use only.**

| | |
|---|---|
| **Document No.** | IFU-UDA-001 |
| **Version** | 0.1 (Draft) |
| **Date** | 2026-05-16 |
| **Languages provided** | English (this revision) |

---

## 1. Symbols Glossary (ISO 15223-1)

| Symbol | Reference | Meaning |
|---|---|---|
| Factory icon | 15223-1 5.1.1 | Manufacturer |
| Date in box | 15223-1 5.1.3 | Date of manufacture |
| Hourglass / expiry | 15223-1 5.1.4 | Use-by date |
| LOT | 15223-1 5.1.5 | Batch / lot code |
| REF | 15223-1 5.1.6 | Catalogue / model number |
| SN | 15223-1 5.1.7 | Serial number |
| Two-arrow recycle | 15223-1 5.4.5 | Single-use (applies to reagent strip, not to device) |
| IVD | 15223-1 5.5.1 | In vitro diagnostic medical device |
| Open book | 15223-1 5.4.3 | Consult instructions for use |
| Exclamation triangle | 15223-1 5.4.4 | Caution |
| Biohazard | 15223-1 5.4.6 (ISO 7010 W009) | Biological hazard |
| UV warning | ISO 7010 W027 | Ultraviolet radiation |
| Crossed-bin | EN 50419 / WEEE | Do not discard in normal waste |
| Temperature range | 15223-1 5.3.7 | Storage temperature limits |
| Humidity range | 15223-1 5.3.8 | Storage humidity limits |
| Umbrella with droplets | 15223-1 5.3.4 | Keep dry |
| Sun-with-cross | 15223-1 5.3.2 | Keep away from sunlight |
| Country of origin | 15223-1 5.1.11 | Country of manufacture |
| Authorised representative | 15223-1 5.1.2 | If applicable |

---

## 2. Indications for Use

The Urine Dipstick Analyzer UDA-PROTO-001 is intended for the **semi-quantitative measurement** of glucose, protein, ketones, bilirubin, blood, pH, urobilinogen, nitrite, leukocytes, and specific gravity in human urine, using commercially available 10-pad reagent strips.

- **Intended user:** clinical laboratory technician, general practitioner, trained healthcare worker.
- **Intended environment:** indoor clinic or laboratory bench; ambient 15–35 °C, 20–80% RH non-condensing, indoor lighting 200–1000 lux.
- **Patient population:** adults and children ≥ 2 years of age.
- **Contraindications:** not for use with paediatric < 2 years; not for testing fluids other than human urine; not for use as a sole determinant in critical-care decisions; not for home use by lay persons.

Results from this device must be interpreted by a qualified healthcare provider in conjunction with clinical findings.

---

## 3. Warnings and Precautions

1. **Biohazard.** Urine is a potentially infectious body fluid. Always wear gloves; avoid splashes; clean the tray between tests.
2. **UV-C radiation.** The device contains a 275 nm UV-C LED used for tray sterilisation. **Do not stare into the chamber or attempt to defeat the tray interlock.** UV-C can cause photokeratitis (eye burns) and skin erythema.
3. **Do not open the device.** No user-serviceable parts are inside. Opening voids warranty and may expose internal hazards.
4. **Do not immerse the device.** It is rated IP22 (drip-resistant from above only). Do not place under running water.
5. **Use only specified reagent strips.** Refer to §5 for the validated brands. Use of other strips may produce inaccurate results.
6. **Do not use expired strips.** Expired reagents give unreliable readings.
7. **Do not place the device in direct sunlight.** Ambient light leakage will saturate the optical reading and produce errors.
8. **Battery safety.** Use only the supplied USB-C charger or a certified USB-C 5 V / 1 A source. Do not puncture, crush, or expose to temperatures above 60 °C. In the event of swelling or unusual heating, stop use immediately and contact service.
9. **Charging environment.** Charge only on a non-flammable, dry surface, in a ventilated area.
10. **EMC.** Maintain ≥ 30 cm distance from active radio-frequency transmitters (e.g., mobile phones in voice mode).
11. **Cleanliness.** Wipe the tray with 70% IPA between tests. Do not use bleach (sodium hypochlorite) — it degrades the EPDM gasket.
12. **No reuse of strips.** Reagent strips are single-use only.
13. **Calibration.** Recalibrate annually or after any service event. Use only the supplied ColorChecker card.
14. **Software updates.** Install firmware updates only when prompted by the device and only from the manufacturer's authorised source.
15. **Disposal.** Do not discard the device or its battery in ordinary refuse; see §14.

---

## 4. Device Description

### 4.1 What's in the box

- Urine Dipstick Analyzer device (1)
- USB-C charging cable (1, 1 m)
- ColorChecker calibration card (1)
- White-balance card (1)
- Quick-start guide (1)
- Full IFU (this document)
- Warranty card (1)

### 4.2 Controls and indicators

- **Front:** 2.4" colour touchscreen TFT (320 × 240)
- **Right side:** tactile push-button (Power / Wake / Run)
- **Top:** strip-tray slot with motorised tray
- **Rear:** USB-C charging port; barcode-scan window (GM65)
- **Bottom:** vent grill, serial-number label, rubber feet (×4)
- **Indicator LED:** RGB status LED on the front panel (Green = ready; Amber = busy; Red = error)
- **Buzzer:** internal piezo (audible alerts)

---

## 5. Compatible Reagent Strips

Calibration tables ship for the following validated brands:

| Brand | Model |
|---|---|
| Siemens | Multistix 10 SG |
| Roche | Combur-10 Test M |
| ARKRAY | AUTION-Sticks 10EA |

Other brands may be added in future firmware updates. The device will refuse to test an unrecognised strip.

---

## 6. Setup

### 6.1 First-time setup

1. Place the device on a flat, dry, level surface, away from direct sunlight and heat sources.
2. Charge fully before first use (~3 h). The RGB LED is amber while charging and green when complete.
3. Power on by pressing the side button for 1 s.
4. Set date, time, and clinic name on the on-screen prompts.
5. From the menu, select **Calibrate** → **Initial Setup**. Insert the supplied ColorChecker card into the tray when prompted and follow the on-screen instructions. The device captures the card and stores the per-device calibration.
6. After successful calibration, the device returns to the main menu. Setup complete.

### 6.2 Routine calibration

Repeat the calibration step every 12 months, or:

- After any service or repair,
- If results trend out of expected ranges in QC,
- If you observe colour-related warning messages on the display.

---

## 7. Performing a Test

1. **Don gloves.** Collect a fresh urine specimen in a clean container.
2. From the main menu, select **Run Test**.
3. When prompted, scan the reagent strip vial's barcode using the rear-window scanner. Wait for the on-screen confirmation of brand, lot, and expiry.
4. Dip a single reagent strip into the urine specimen for 1 s, then briefly tap the edge against the container rim to remove excess fluid.
5. Place the strip on the tray with the reagent pads facing up, aligned with the imprinted guide marks. *[See Figure 1 — strip placement diagram.]*
6. Press the side button to start. The tray closes automatically; the indicator LED turns amber.
7. The display shows a countdown to result. Do not open the tray during this period.
8. When the reading is complete, the LED returns to green and the buzzer chirps once. Results are displayed.
9. Open the tray, dispose of the strip in a biohazard bag, and wipe the tray surface with a 70% IPA wipe.
10. The device begins a 30-s UV-C sterilisation cycle automatically. The display shows "Sterilising — do not open." Wait for the cycle to complete before the next test.

---

## 8. Reading Results

The display shows each of the 10 analytes with a semi-quantitative category. The reference ranges (per Siemens Multistix labelling) are:

| Analyte | Categories shown | Typical normal |
|---|---|---|
| Glucose | Neg, 100, 250, 500, 1000, 2000 mg/dL | Negative |
| Bilirubin | Neg, Small, Mod, Large | Negative |
| Ketones | Neg, Trace, Small, Mod, Large | Negative |
| Specific Gravity | 1.000–1.030 | 1.005–1.030 |
| Blood | Neg, Trace, Small, Mod, Large | Negative |
| pH | 5.0, 5.5, 6.0, 6.5, 7.0, 7.5, 8.0, 8.5, 9.0 | 5.5–7.0 |
| Protein | Neg, Trace, 30, 100, 300, 2000 mg/dL | Negative–Trace |
| Urobilinogen | 0.2, 1, 2, 4, 8 mg/dL | 0.2–1.0 |
| Nitrite | Neg, Positive | Negative |
| Leukocytes | Neg, Trace, Small, Mod, Large | Negative |

Tap any row on the display to see a clinical-notes pop-up.

---

## 9. Quality Control

- **Frequency:** at start of each shift, after any maintenance, and after firmware update.
- **Materials:** positive and negative urinalysis control solutions (e.g., BioRad Liquichek Urinalysis Control levels 1 and 2).
- **Workflow:** Menu → **QC** → follow prompts. Results are stored in a QC log separate from patient data.
- **Failure handling:** if a QC result is out of expected range, repeat with a fresh strip. Persistent failure indicates the need for recalibration or service.

---

## 10. Cleaning and Disinfection

**Allowed agents:**
- 70% isopropyl alcohol (IPA) wipes
- Quaternary ammonium compound wipes (e.g., CaviWipes)

**Prohibited agents:**
- Sodium hypochlorite (bleach) — degrades EPDM gasket
- Acetone, methylethylketone — attacks PETG
- Hydrogen peroxide > 3% — may discolour optics
- Abrasive cleaners

**Procedure:**
- Power off the device.
- Wipe the tray with a single IPA wipe. Allow 60 s contact time.
- Wipe the external enclosure with a damp lint-free cloth, then dry.
- Do not immerse. Do not spray cleaner directly onto the device.

---

## 11. Storage and Transport

- **Storage temperature:** 5 to 40 °C
- **Storage humidity:** 10–90% RH, non-condensing
- **Operating temperature:** 15 to 35 °C
- **Operating humidity:** 20–80% RH, non-condensing
- **Shock / vibration during transport:** withstands packaged 1 m drop per ISTA 1A
- **Long-term storage:** charge the battery every 6 months to prevent deep discharge.

---

## 12. Troubleshooting

| Code | Message | Possible cause | Remedy |
|---|---|---|---|
| E-01 | Camera not detected | DVP cable loose | Power-cycle; if persistent, service |
| E-02 | Ambient light too high | Direct sunlight or open chamber | Move device; close tray; retry |
| E-03 | Strip not recognised | Barcode unreadable / unsupported brand | Use a supported strip; clean barcode window |
| E-04 | Strip expired | Use-by date passed | Use a fresh vial |
| E-05 | Battery low | Below 5% SoC | Charge before testing |
| E-06 | UV interlock open | Tray not closed or reed switch fault | Close tray; if persistent, service |
| E-07 | Storage full / SD error | SD missing or corrupt | Insert/replace SD card |
| E-08 | Calibration data invalid | Hash mismatch | Re-run calibration |
| E-09 | Heater fault | SHT31 fault or thermal cut | Power-cycle; service |
| E-10 | Stepper home miss | Limit-switch fault | Power-cycle; service |

If an error persists, contact the manufacturer (see §15).

---

## 13. Specifications

| Item | Specification |
|---|---|
| Analytes measured | 10 (glucose, protein, ketones, bilirubin, blood, pH, urobilinogen, nitrite, leukocytes, specific gravity) |
| Sample type | Human urine on commercial reagent strip |
| Accuracy claim | ≥ 90% category agreement with predicate device, **per analyte; to be confirmed in clinical V&V** |
| Repeatability | CV ≤ 10% on triplicate reads, **to be measured during V&V** |
| Time to result | ≤ 120 s |
| Throughput | Up to 30 tests per hour |
| Display | 2.4" colour TFT, 320 × 240 |
| User input | Touchscreen + 1 tactile button |
| Connectivity | USB-C (charge + data); barcode scan (UART, internal) |
| Storage | Up to 1 000 records on internal microSD |
| Battery | 3.7 V / 1000 mAh LiPo, ≥ 50 tests per charge |
| Charge | USB-C, 5 V / 1 A, ~3 h to full |
| Sterilisation | 275 nm UV-C, 30 s per cycle |
| Dimensions | 180 × 120 × 40 mm |
| Weight | ~ 350 g |
| Electrical | SELV throughout; ≤ 5 V internal |
| Operating environment | 15–35 °C, 20–80% RH non-condensing |
| Storage environment | 5–40 °C, 10–90% RH non-condensing |
| IP rating | IP22 |

*Accuracy and repeatability figures will be finalised after design verification and clinical evaluation.*

---

## 14. Disposal

The device contains electronic components and a rechargeable lithium-polymer battery, both regulated under the **E-Waste (Management) Rules, 2022** of India.

- **Before disposal,** wipe all external surfaces with 70% IPA to remove any biological residue. The tray is the only surface that contacted patient samples.
- **Do not** dispose of the device or the battery in regular municipal waste.
- Return the device to the manufacturer's take-back programme, or hand it to an authorised e-waste collector.
- Battery: do not puncture or incinerate. If swollen, place in a sand-filled metal container before transport.

---

## 15. Manufacturer and Service Contact

| | |
|---|---|
| Manufacturer | Siddhant Saboo (sole proprietor) |
| Address | [Address line 1, India — TBD] |
| Phone | [TBD] |
| Email | siddhantsaboo@gmail.com |
| Manufacturing licence number | [MD-TBD] (to be issued by State Licensing Authority) |
| Service hours | Mon–Fri, 09:00–18:00 IST |

For complaints, adverse events, or unexpected device behaviour, contact the manufacturer immediately. Adverse events involving patient harm should additionally be reported to the **Materiovigilance Programme of India** (MvPI), CDSCO.

---

## 16. Revision History

| Version | Date | Change | Author |
|---|---|---|---|
| 0.1 | 2026-05-16 | Initial draft for internal review | S. Saboo |

---

*End of IFU v0.1.*

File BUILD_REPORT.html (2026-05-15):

# Urine Dipstick Analyzer -- Comprehensive Build Report

Document Version: 1.0
Date: 2026-05-15
Target Market: India (CDSCO-regulated)
Platform: ESP32-S3 MCU with OV2640 Camera

## Table of Contents

1. Scientific Principle and Method
2. Optical Design
3. Full Bill of Materials with Costs
4. PCB Design Notes
5. Mechanical Assembly Instructions
6. Firmware Overview
7. Calibration Procedure
8. Regulatory Considerations for India

## 1. Scientific Principle and Method

### 1.1 Reflectance Photometry Overview

The Urine Dipstick Analyzer operates on the principle of reflectance photometry (also called colorimetric analysis). A urine dipstick is a narrow plastic strip with 10 discrete reagent pads bonded along its length. Each pad contains dried chemical reagents specific to a single analyte. When the strip is dipped in a urine sample, the reagent pads absorb the specimen and undergo chemical reactions that produce a visible color change. The intensity and hue of that color change are proportional to the concentration of the target analyte in the sample.

In traditional manual reading, a trained technician visually compares each pad against a printed color chart supplied by the strip manufacturer. This method is inherently subjective, operator-dependent, and prone to timing errors. Automated reflectance photometry eliminates these variables by using a controlled light source, a calibrated image sensor, and algorithmic color quantification to produce consistent, reproducible results.

### 1.2 Parameters Measured

The device measures 10 standard urinalysis parameters. Each parameter, its underlying chemical reaction, and clinical significance are summarized below.

Parameter | Reagent Chemistry | Clinical Range | Clinical Significance
Glucose | Glucose oxidase / peroxidase | Negative to 2000 mg/dL | Diabetes screening, glycosuria
Protein (Albumin) | Tetrabromophenol blue (protein error of indicators) | Negative to 2000 mg/dL | Kidney disease, proteinuria
pH | Methyl red + bromothymol blue | 5.0 -- 9.0 | Acid-base status, UTI, renal tubular acidosis
Specific Gravity | Polyionic electrolyte complex | 1.000 -- 1.030 | Hydration status, concentrating ability
Ketones | Sodium nitroprusside (Legal test) | Negative to 160 mg/dL | Diabetic ketoacidosis, starvation
Bilirubin | Diazotized dichloroaniline | Negative to 6 mg/dL | Liver disease, biliary obstruction
Urobilinogen | Modified Ehrlich reagent | 0.2 -- 8.0 mg/dL | Hemolysis, liver function
Blood / Hemoglobin | Pseudoperoxidase activity of hemoglobin | Negative to 250 RBC/uL | Hematuria, kidney stones, infection
Nitrite | Griess reaction (aromatic amine + coupling agent) | Negative / Positive | Bacteriuria (gram-negative organisms)
Leukocytes | Esterase hydrolysis of indoxyl derivative | Negative to 500 WBC/uL | Urinary tract infection, inflammation

### 1.3 Measurement Principle

The measurement workflow proceeds as follows:

1. The urine-wetted dipstick is placed on the motorized tray.
2. After a manufacturer-specified reaction time (typically 60--120 seconds), the tray advances the strip to the imaging position.
3. A white LED array illuminates the strip under controlled, diffuse lighting conditions.
4. The OV2640 camera captures a high-resolution image of the strip surface.
5. Firmware extracts a Region of Interest (ROI) for each reagent pad.
6. The RGB pixel values within each ROI are converted to HSV color space for analysis.
7. The measured HSV triplet is compared against pre-stored calibration lookup tables (derived from known-concentration calibration strips).
8. A polynomial fitting function maps the color values to analyte concentration.
9. The concentration is classified into semiquantitative clinical categories: Negative, Trace, 1+, 2+, 3+, 4+ (or specific mg/dL ranges, depending on the analyte).

### 1.4 Applicable Standards

- CLSI GP16-A3 -- Urinalysis: Approved Guideline (specimen handling, strip reading timing, QC)
- ISO 15197 -- In vitro diagnostic test systems (performance requirements)
- ISO 14971 -- Application of risk management to medical devices

## 2. Optical Design

### 2.1 LED Illumination System

Uniform, repeatable illumination is critical for accurate colorimetric measurement. The illumination subsystem consists of:

- Light Source: 5V white LED array module (color temperature ~5500K, daylight-equivalent). A single module provides sufficient flux for the small imaging area (~120 x 25 mm strip surface).
- Diffuser: A frosted acrylic diffuser panel (30 x 20 x 1 mm) is placed between the LED array and the dipstick surface. This converts the point-source LED output into spatially uniform, diffuse illumination across the entire strip length.
- Illumination Geometry: The LED/diffuser assembly is mounted at a 45-degree angle relative to the strip surface. This angled illumination minimizes specular (mirror-like) reflections from the wet reagent pads, which would otherwise saturate the camera sensor and corrupt color readings.
- Light Isolation: The interior of the measurement chamber is lined with self-adhesive flocking sheet (black, velvet-like material). This absorbs stray light and prevents internal reflections that could contaminate the measurement.

### 2.2 Imaging System

- Camera: OV2640 module, 2 megapixel (1600 x 1200 resolution), connected via DVP (Digital Video Port) interface to the ESP32-S3. The DVP interface provides faster frame transfer than SPI-based camera modules, which is important for the 8-bit RGB565 or JPEG capture modes used during analysis.
- Polarizer: A circular polarizer (CPL) filter is attached to the camera lens. The CPL further rejects specular reflections from the wet, glossy surface of reagent pads. This is especially important for pads that remain visibly moist during reading.
- Working Distance: The camera is fixed at approximately 50 mm from the strip surface. At this distance, the camera field of view covers the full 10-pad strip length with sufficient pixel density for per-pad ROI extraction (~80-100 pixels per pad).
- Focus: Fixed focus, preset at the dipstick plane during assembly. No autofocus mechanism is required because the strip-to-camera distance is mechanically constrained by the tray and mount geometry.

### 2.3 Color Calibration System

- Color Calibration Card: A printed reference card (20 x 10 mm) with known color patches is permanently mounted on the dipstick tray surface, adjacent to the strip position. Every captured image includes these reference patches, enabling firmware-based drift compensation.
- White Balance Target Card: A separate mini gray/white card provides a known-reflectance surface for automatic white balance correction. This compensates for LED aging and temperature-dependent color shifts.
- Ambient Light Sensor: A BH1750 digital ambient light sensor (I2C interface) is mounted inside the measurement chamber. It detects any ambient light leakage through the tray aperture or enclosure seams. If ambient light exceeds a threshold (>5 lux), the firmware delays measurement until conditions are stable, or alerts the operator to close the tray fully.

### 2.4 UV-C Sterilization System

Urine dipstick analysis involves biological specimens, and cross-contamination between successive tests is a concern. The device includes an integrated UV-C sterilization stage:

- UV-C LED: A 275 nm UV-C LED module is mounted above the tray in the retracted (home) position. After each measurement, the tray retracts to the UV-C exposure zone and the LED operates for 30 seconds, delivering germicidal irradiance to the tray surface.
- UV Window: A quartz glass window (20 x 20 mm, UV-transparent) protects the camera lens from UV exposure while allowing transmission at 275 nm. Standard glass or acrylic would absorb UV-C radiation.
- Safety Interlock: An MC-38 magnetic reed switch is mounted at the tray aperture. The switch detects whether the tray is retracted and the chamber is sealed before allowing UV-C activation. If the tray is extended or the chamber is open, UV-C emission is hardware-blocked via MOSFET gate control.
- UV Shielding: EPDM foam gaskets are installed at all seams and joints in the UV-C zone to prevent UV light leakage to the exterior. EPDM rubber is highly resistant to UV degradation.

## 3. Full Bill of Materials with Costs

### 3.1 Electrical Components

Component | Description | Qty | Unit Cost (USD) | Total (USD) | Source
ESP32-S3-DevKitC-1-N8R8 | Main MCU, 8MB PSRAM for image processing | 1 | 15.00 | 15.00 | DigiKey
OV2640 Camera + CPL | Camera module with circular polarizer filter | 1 | 22.00 | 22.00 | Amazon
SSD1306 OLED Display | 0.96" I2C monochrome display, 128x64 px | 1 | 5.00 | 5.00 | Amazon
White LED Array | 5V LED module, ~5500K color temp | 1 | 3.00 | 3.00 | Amazon
3.7V 1000mAh LiPo | Rechargeable lithium polymer battery | 1 | 10.00 | 10.00 | Amazon
MCP73833 USB-C Charger | LiPo charge management IC breakout | 1 | 12.50 | 12.50 | Adafruit
Pololu S13V25F9 | 9V/5V buck-boost voltage regulator | 1 | 12.00 | 12.00 | Pololu
Pololu S7V8F3 | 3.3V buck-boost voltage regulator | 1 | 6.00 | 6.00 | Pololu
Power Distribution PCB | Custom 2-layer power management hub | 1 | 5.00 | 5.00 | OSHPark
A4988 Stepper Driver | Bipolar stepper motor driver, adjustable current | 1 | 5.00 | 5.00 | Amazon
NEMA 17 Stepper Motor | 20mm body length, 200 steps/rev, 12V rated | 1 | 12.00 | 12.00 | Amazon
SHT31-D | Digital temperature and humidity sensor (I2C) | 1 | 12.00 | 12.00 | Adafruit
BH1750 | Digital ambient light sensor module (I2C) | 1 | 4.50 | 4.50 | Amazon
10K NTC Thermistor | Tray surface temperature sensing | 1 | 0.50 | 0.50 | Amazon
GM65 Barcode Scanner | QR/barcode reader module (UART interface) | 1 | 28.00 | 28.00 | Amazon
Micro SD Card Module | SPI interface, data logging | 1 | 4.00 | 4.00 | Amazon
275nm UV-C LED | Germicidal sterilization LED | 1 | 15.00 | 15.00 | DigiKey
Polyimide Heater Film | 25x50mm, 5V, ~2W | 1 | 8.00 | 8.00 | Amazon
30mm 5V DC Fan | Chamber ventilation and cooling | 1 | 5.00 | 5.00 | Amazon
5V Active Piezo Buzzer | Audible alerts and notifications | 1 | 1.50 | 1.50 | Amazon
RGB LED (Common Anode) | Status indicator (R/G/B channels) | 1 | 0.50 | 0.50 | Amazon
Tactile Push Button 6x6mm | Measure trigger, menu navigation | 1 | 0.50 | 0.50 | Amazon
MC-38 Reed Switch | Magnetic safety interlock sensor | 1 | 4.00 | 4.00 | Amazon
Micro Limit Switch | Tray home position detection | 1 | 2.00 | 2.00 | Amazon
2N7000 MOSFET (N-ch) | Fan control switching | 1 | 0.50 | 0.50 | Amazon
IRLZ44N MOSFET (N-ch) | UV LED driver (logic-level gate) | 1 | 1.00 | 1.00 | Amazon
IRLZ44N MOSFET (N-ch) | Heater control switching | 1 | 1.00 | 1.00 | Amazon
Resistors (assorted) | Pull-ups, current limiters, voltage dividers | ~20 | 0.05 | 1.00 | Local
Capacitors (assorted) | 100nF ceramic decoupling, 10uF bulk | ~15 | 0.05 | 0.75 | Local

Electrical Subtotal: $197.25

### 3.2 Mechanical Components

Component | Description | Qty | Unit Cost (USD) | Total (USD) | Source
Molded Enclosure Base | 180x120x40mm ABS/PETG, main housing | 1 | 25.00 | 25.00 | 3D print / mold
Enclosure Top Cover | 180x120x5mm PETG, snap-fit or screw mount | 1 | 7.00 | 7.00 | 3D print
Molded Dipstick Tray | 120x25x8mm, strip channel with calibration card recess | 1 | 10.00 | 10.00 | 3D print / mold
Camera and LED Mount | 40x30x25mm PETG bracket, 45-degree LED angle | 1 | 4.00 | 4.00 | 3D print
Scanner Mount | 35x25x15mm bracket for GM65 barcode module | 1 | 3.00 | 3.00 | 3D print
Vent Grill | 35x35mm slotted panel for fan exhaust | 1 | 2.00 | 2.00 | 3D print
Cable Management Frame | 160x100x10mm internal skeleton for routing wires | 1 | 2.00 | 2.00 | 3D print
T8 Lead Screw + Nut | 100mm linear actuator, 2mm pitch | 1 | 8.00 | 8.00 | Amazon
M2x6mm Screws | PCB and module mounting | 12 | 0.05 | 0.60 | Amazon
M3x8mm Screws | Enclosure cover attachment | 4 | 0.10 | 0.40 | Amazon
M3 Heat-Set Inserts | Brass threaded inserts for PETG | 4 | 0.20 | 0.80 | Amazon
M2.5 Standoffs (kit) | PCB mounting standoff set (M/F, various lengths) | 1 | 4.00 | 4.00 | Amazon
Silicone Gasket | 98x68x1mm chamber seal | 1 | 3.00 | 3.00 | Amazon
Frosted Acrylic Diffuser | 30x20x1mm, light diffusion panel | 1 | 2.00 | 2.00 | Amazon
Color Calibration Card | 20x10mm printed color reference patches | 1 | 1.00 | 1.00 | Amazon
White Balance Card | Mini gray/white reference card | 1 | 5.00 | 5.00 | Amazon
Quartz Glass Window | 20x20mm UV-transparent window | 1 | 8.00 | 8.00 | Amazon
Flocking Sheet | Self-adhesive black light absorber, A4 sheet | 1 | 10.00 | 10.00 | Amazon
EPDM Foam Gasket | UV shielding strips, adhesive-backed | 1 | 5.00 | 5.00 | Amazon

Mechanical Subtotal: $100.80

### 3.3 Cost Summary

Category | Cost (USD)
Electrical Components | $197.25
Mechanical Components | $100.80
Prototype Total | ~$298
Estimated Volume Cost (100+ units) | $180 -- $220

Volume cost reductions come from: bulk component pricing (30--40% savings on passives and modules), injection-molded enclosure parts replacing 3D prints, and consolidated PCB assembly replacing hand-wired breakout boards.

## 4. PCB Design Notes

### 4.1 Architecture

The prototype uses the ESP32-S3-DevKitC-1 development board as the main controller, paired with a custom Power Distribution PCB that centralizes voltage regulation, decoupling, and ground management.

For production, these should be consolidated into a single application-specific PCB carrying the ESP32-S3 module (ESP32-S3-WROOM-1) directly, along with all power management, sensor interfaces, and driver circuits.

### 4.2 Power Distribution PCB

- Layer Count: 2-layer FR-4, 1.6mm thickness, 1oz copper
- Dimensions: Approximately 50 x 40 mm
- Function: Accepts 3.3V and 5V from the buck-boost regulators and distributes to all subsystems with per-rail decoupling and protection

### 4.3 Grounding Strategy

- Star grounding topology: Separate analog and digital ground planes converge at a single star point near the power entry. This prevents digital switching noise (stepper driver, ESP32 clock) from coupling into the analog sensor readings (thermistor ADC, camera DVP bus).
- The camera DVP data bus and the I2C sensor bus should be routed on opposite sides of the PCB with a ground pour separating them.

### 4.4 Decoupling

- 100nF ceramic capacitor placed within 5mm of every IC power pin (ESP32-S3, SHT31, BH1750, OLED driver, A4988)
- 10uF electrolytic or tantalum bulk capacitor on each power rail at the point of entry to the PCB
- 100uF electrolytic on the stepper driver VMOT pin (required by A4988 datasheet to absorb back-EMF spikes)

### 4.5 Interface Bus Layout

Bus | Signals | GPIO Assignments | Notes
I2C | SCL, SDA | GPIO18 (SCL), GPIO19 (SDA) | 4.7K ohm pull-ups to 3.3V; max 3 devices
SPI (SD Card) | MOSI, MISO, SCK, CS | GPIO38, GPIO39, GPIO40, GPIO41 | Dedicated bus, no shared devices
DVP (Camera) | D0-D7, PCLK, VSYNC, HREF, XCLK | Per ESP32-S3 DVP pin map | Short traces, matched length preferred
UART (Scanner) | TX, RX | GPIO43 (TX), GPIO44 (RX) | 9600 baud default for GM65
Stepper | STEP, DIR | GPIO4 (STEP), GPIO16 (DIR) | 100 ohm series resistors recommended

### 4.6 MOSFET Driver Circuits

All three MOSFET-switched loads (fan, UV LED, heater) use identical driver topology:

- Gate: Connected to ESP32 GPIO via 100 ohm series resistor (limits inrush current to gate capacitance)
- Gate Pull-Down: 10K ohm resistor from gate to ground (ensures load is OFF during ESP32 boot/reset when GPIOs are floating)
- Drain: Connected to load negative terminal
- Source: Connected to ground
- Flyback Diode: 1N4007 across the fan motor terminals (suppresses inductive kick)

### 4.7 Production Recommendations

- Move to a 4-layer stackup (Signal / Ground / Power / Signal) for the production board. This provides a continuous ground plane for EMI control and simplifies routing.
- Add ESD protection (TVS diodes) on the USB-C connector, UART lines, and any external-facing connectors.
- Add reverse polarity protection (P-channel MOSFET) on the battery input.
- Recommended fabricators: JLCPCB (lowest cost, fast turnaround), OSHPark (higher quality, US-based), or local Indian PCB shops for rapid iteration.

## 5. Mechanical Assembly Instructions

### Phase 1: Part Fabrication and Preparation

1. 3D print all mechanical parts. Use PETG filament (preferred for chemical resistance and moderate heat tolerance) or ABS. Print internal parts (cable frame, mounts) in black to minimize internal reflections. Print the enclosure base and cover in the desired product color (white or light gray recommended for a clinical appearance).
2. Install M3 heat-set inserts into the four corner mounting holes of the enclosure base. Use a soldering iron set to 220C with a heat-set insert tip. Press each insert flush with the surface.
3. Apply flocking material. Cut self-adhesive flocking sheet to fit the interior surfaces of the measurement chamber (the area around the camera and LED mount). Peel and apply, pressing firmly to remove air bubbles.
4. Prepare the dipstick tray. Attach the color calibration card and white balance card to their respective recesses on the tray surface using thin double-sided adhesive tape.
5. Install optical elements. Press-fit the quartz glass window into the camera mount aperture. Press-fit the frosted acrylic diffuser into the LED mount slot.

### Phase 2: Electrical Wiring

Power chain (wire first, verify before connecting MCU):

1. Solder the LiPo battery connector to the MCP73833 USB-C charger board input.
2. Connect charger board output to the input of both buck-boost regulators (Pololu S13V25F9 for 9V/5V and Pololu S7V8F3 for 3.3V). Use a solder-bridge jumper or small slide switch for a master power cutoff.
3. Route regulator outputs to the power distribution PCB input terminals.

3.3V rail distribution (from power PCB):

1. ESP32-S3 DevKit 3.3V pin, SSD1306 OLED VCC, SHT31-D VCC, BH1750 VCC, GM65 barcode scanner VCC, SD card module VCC, tactile button pull-up, RGB LED anodes (via current-limiting resistors), buzzer logic supply.

5V rail distribution:

1. Fan positive (through 2N7000 MOSFET drain), UV-C LED anode (through IRLZ44N MOSFET drain with appropriate current-limiting resistor -- calculate based on UV LED forward voltage and desired drive current), polyimide heater (through IRLZ44N MOSFET drain), white LED array VCC.

9V rail:

1. A4988 stepper driver VMOT pin (with 100uF decoupling capacitor across VMOT and GND).

Signal wiring:

1. I2C bus: Wire GPIO18 (SCL) and GPIO19 (SDA) from ESP32 to SSD1306, SHT31-D, and BH1750 in a daisy-chain topology. Install 4.7K ohm pull-up resistors from SCL and SDA to 3.3V at the ESP32 end of the bus.
2. SPI bus: Wire GPIO38 (MOSI), GPIO39 (MISO), GPIO40 (SCK), GPIO41 (CS) to the SD card module.
3. Stepper driver: Wire GPIO4 to A4988 STEP input, GPIO16 to A4988 DIR input. Connect A4988 motor outputs (1A, 1B, 2A, 2B) to NEMA 17 motor windings per the motor datasheet.
4. MOSFET gates: Wire ESP32 GPIOs to each MOSFET gate via 100 ohm series resistor. Install 10K ohm pull-down resistors from each gate to ground.
5. Camera DVP bus: Connect OV2640 module to ESP32-S3 DVP pins per the ESP32-S3 camera pinout reference. This is typically an 8-bit parallel data bus plus PCLK, VSYNC, HREF, XCLK, SIOD, and SIOC.
6. Barcode scanner UART: Wire GM65 TX to ESP32 GPIO44 (RX), GM65 RX to ESP32 GPIO43 (TX).
7. Safety interlock: Wire MC-38 reed switch between GPIO21 and ground (enable internal pull-up in firmware).
8. Limit switch: Wire micro limit switch between GPIO15 and ground (enable internal pull-up in firmware).
9. Thermistor: Wire 10K NTC in a voltage divider (10K NTC + 10K fixed resistor) to an ESP32 ADC-capable GPIO.
10. Button: Wire tactile switch between a GPIO and ground (enable internal pull-up).
11. Buzzer: Wire to a GPIO (active buzzer, digital HIGH = ON).
12. RGB LED: Wire each color channel (R, G, B) through a 330 ohm current-limiting resistor to individual ESP32 GPIOs. Common anode connects to 3.3V.

### Phase 3: Bring-Up and Verification

1. Power rail verification. Before connecting the ESP32 or any sensor modules, power on the system and measure all rails with a multimeter: 3.3V (+/- 0.1V), 5V (+/- 0.25V), 9V (+/- 0.5V). Verify that MOSFETs are OFF (gate pull-downs holding loads off).
2. Flash firmware. Connect ESP32-S3 via USB-C and flash the firmware using idf.py flash (ESP-IDF) or Arduino IDE upload.
3. I2C device scan. Run an I2C scanner sketch to verify all three devices respond: OLED at 0x3C, SHT31 at 0x44, BH1750 at 0x23.
4. Stepper calibration. Command the stepper to advance slowly until the limit switch triggers. Record the step count as the home position. Measure the total travel from home to the camera imaging position and program the target step count.
5. Camera test. Initialize the OV2640 in JPEG mode, capture a test frame, and verify image quality on the OLED or via serial output to a PC.
6. White balance calibration. Capture an image of the white balance card under LED illumination. Record the reference RGB values and store in NVS flash.
7. Heater PID tuning. Enable the heater and monitor the thermistor reading. Tune PID constants (Kp, Ki, Kd) to achieve a stable 37C setpoint with less than 1C overshoot. This temperature optimizes enzyme reaction kinetics on the reagent pads.
8. UV-C interlock test. With the tray extended (chamber open), attempt to activate the UV-C LED via firmware. Verify that the reed switch interlock prevents activation. Retract the tray (chamber closed) and verify UV-C activates.
9. Barcode scanner test. Present a QR code to the GM65 module and verify UART data reception on the ESP32.

### Phase 4: Final Assembly

1. Mount the ESP32 DevKit and power distribution PCB to the cable management frame using M2.5 standoffs and M2x6mm screws.
2. Install the tray mechanism: attach the NEMA 17 motor to the enclosure base, install the T8 lead screw through the tray nut, and verify smooth linear travel.
3. Secure the camera/LED mount to the enclosure base above the tray imaging position. Verify alignment by capturing a test image of a dipstick on the tray.
4. Mount the GM65 scanner bracket at the tray entry point.
5. Route all wiring through the cable management frame channels. Use small cable ties or adhesive clips to secure loose wires away from moving tray parts.
6. Install the silicone gasket around the perimeter of the measurement chamber opening.
7. Install EPDM foam gaskets around the UV-C LED zone to seal UV light leakage paths.
8. Install the vent grill in the enclosure wall (snap-fit design) and mount the 30mm fan behind it.
9. Place the enclosure top cover and secure with four M3x8mm screws into the heat-set inserts.
10. Perform a final functional test: full measurement cycle (insert strip, press button, capture, analyze, display, sterilize).

## 6. Firmware Overview

### 6.1 Architecture

- Platform: ESP-IDF v5.x (recommended for full hardware control and PSRAM management) or Arduino-ESP32 core for faster prototyping.
- Processor: ESP32-S3 dual-core Xtensa LX7 at 240 MHz.
- Memory: 8MB PSRAM (external, accessed via OPI interface) is essential for holding camera frame buffers. A single 1600x1200 RGB565 frame consumes approximately 3.75 MB. PSRAM also holds the color lookup tables and image processing buffers.
- Storage: Internal NVS (Non-Volatile Storage) partition for calibration coefficients, device settings, and usage counters. External Micro SD card for CSV data logging.

### 6.2 State Machine

The main firmware loop operates as a state machine with the following states:

IDLE --> SCAN_BARCODE --> WAIT_REACTION --> CAPTURE --> ANALYZE --> DISPLAY --> LOG --> STERILIZE --> IDLE

State | Description | Duration
IDLE | Awaiting button press, showing status on OLED | Indefinite
SCAN_BARCODE | Optional: scan patient ID or reagent lot QR code | 5 seconds timeout
WAIT_REACTION | Countdown timer for reagent reaction (60--120 sec) | Configurable
CAPTURE | Advance tray, turn on LED, capture camera image | ~2 seconds
ANALYZE | ROI extraction, color quantification, classification | ~3 seconds
DISPLAY | Show results on OLED, beep buzzer for completion | Until dismissed
LOG | Write CSV record to SD card | <1 second
STERILIZE | Retract tray, run UV-C for 30 seconds | 30 seconds

### 6.3 Key Firmware Modules

1. Camera Driver -- OV2640 initialization via SCCB (I2C-like) protocol, register configuration for resolution, exposure, gain, white balance. DVP capture in RGB565 mode for color analysis or JPEG mode for storage. Frame buffer allocated in PSRAM.
2. Image Processing -- ROI extraction using predefined pixel coordinates for each of the 10 reagent pads (coordinates determined during calibration setup). Median filter (3x3 kernel) applied within each ROI to reject salt-and-pepper noise. RGB-to-HSV conversion for each pad region. Mean H, S, V values computed for the ROI.
3. Color Analysis -- Each pad's measured HSV triplet is compared against a calibration lookup table stored in NVS. The lookup table contains HSV values for each concentration level (typically 5--7 levels per analyte). A polynomial curve fit (second or third order) interpolates between calibration points to determine the analyte concentration. The result is then classified into the nearest semiquantitative category.
4. Calibration Engine -- Manages factory calibration data, daily QC validation, and field recalibration. Stores per-pad polynomial coefficients, temperature compensation factors, and white balance reference values in NVS flash. Provides an OLED-guided recalibration workflow.
5. Stepper Control -- Uses the AccelStepper library (or equivalent ESP-IDF driver) for smooth acceleration/deceleration profiles. Homing sequence runs at startup: the stepper retracts until the limit switch triggers, then the step counter resets to zero. Target positions for each pad are stored as step offsets from home.
6. Thermal Control -- PID control loop for the polyimide heater. Setpoint: 37C (body temperature, optimal for most dipstick enzyme reactions). Process variable: NTC thermistor reading via ADC. Control output: PWM duty cycle to the heater MOSFET. Ambient temperature and humidity monitored by SHT31-D for environmental compensation.
7. Display Manager -- SSD1306 OLED driver (using U8g2 or Adafruit SSD1306 library). Implements a menu system: main results screen, scrollable parameter list, history browser, settings menu, calibration mode, and QC status display. 128x64 pixel resolution constrains layout to compact, text-focused interfaces.
8. Data Logger -- Writes CSV records to the Micro SD card via SPI. Each record contains: timestamp (from RTC or NTP if WiFi available), patient ID (from barcode scanner), all 10 parameter results (semiquantitative category and raw HSV values), ambient temperature, humidity, and QC status flag.
9. Barcode Scanner Interface -- GM65 UART protocol handler. Parses scanned QR codes or barcodes for patient ID strings and reagent lot numbers. Lot numbers enable automatic selection of the correct calibration table if multiple strip brands are supported.
10. Safety Manager -- Continuously monitors: reed switch state (UV interlock), thermistor for over-temperature (shutdown heater above 50C), battery voltage via ADC (low-battery warning below 3.4V, shutdown below 3.2V), ambient light level (measurement inhibit if chamber is not dark).

### 6.4 Measurement Workflow (Detailed)

1. User places urine-wetted dipstick on tray and presses the Measure button.
2. (Optional) GM65 scans patient ID barcode if present on the strip packaging or a label.
3. OLED displays a countdown timer for the reagent reaction period (configurable, default 120 seconds for most commercial strips).
4. When the timer expires, the stepper motor advances the tray into the measurement chamber.
5. The limit switch confirms the tray has cleared the aperture; the reed switch confirms chamber closure.
6. The white LED array is powered on. The firmware waits 200 ms for LED thermal stabilization.
7. The BH1750 sensor confirms illumination levels are within the expected range.
8. The OV2640 captures a single frame in RGB565 mode, stored in PSRAM.
9. The white LED is turned off.
10. The firmware identifies the calibration card region in the image, measures its RGB values, and computes a per-channel gain correction relative to the stored reference values.
11. For each of the 10 reagent pads, the firmware extracts the ROI, applies median filtering, converts to HSV, and applies the gain correction.
12. Each pad's corrected HSV values are mapped to an analyte concentration via the stored polynomial calibration curves.
13. Concentrations are classified into semiquantitative categories.
14. Results are displayed on the OLED.
15. A CSV record is appended to the SD card.
16. The buzzer sounds a completion tone.
17. The stepper retracts the tray to the home position (UV-C zone).
18. The UV-C LED activates for 30 seconds (with interlock verification).
19. The UV-C LED turns off, and the system returns to IDLE.

## 7. Calibration Procedure

### 7.1 Initial Factory Calibration

Factory calibration establishes the baseline color-to-concentration mapping for each analyte. This must be performed once during manufacturing, using manufacturer-supplied calibration strips with known analyte concentrations.

Step 1: White Balance

1. Insert a blank (unreacted) dipstick strip onto the tray.
2. Run the measurement sequence.
3. Record the RGB values for the white balance card region. These become the reference white point.
4. Record the RGB values for each unreacted pad. These become the "negative" baseline for each analyte.
5. Store all reference values in NVS flash.

Step 2: Multi-Level Calibration

For each of the 10 analytes, measure calibration strips at 5 known concentration levels:

Level | Example (Glucose) | Example (Protein)
Level 0 (Negative) | 0 mg/dL | 0 mg/dL
Level 1 (Trace/Low) | 100 mg/dL | 15 mg/dL
Level 2 (Moderate) | 250 mg/dL | 30 mg/dL
Level 3 (High) | 500 mg/dL | 100 mg/dL
Level 4 (Very High) | 2000 mg/dL | 2000 mg/dL

For each level, capture the image and record the H, S, V values for the corresponding pad. This yields a 5-point calibration dataset per analyte.

Step 3: Curve Fitting

Fit a second-order polynomial to each analyte's calibration data:

Concentration = a0 + a1*H + a2*S + a3*V + a4*H^2 + a5*S^2 + a6*V^2

The coefficients (a0 through a6) are stored in NVS flash. At measurement time, the firmware evaluates this polynomial with the measured H, S, V values to determine the concentration.

Step 4: Linearity Verification

After curve fitting, verify monotonicity: as the known concentration increases, the predicted concentration must also increase without sign reversals. Non-monotonic behavior indicates a bad calibration point or an inappropriate polynomial order.

Step 5: Temperature Compensation

Repeat the full calibration at four temperatures: 20C, 25C, 30C, and 35C (controlled by the internal heater and SHT31 monitoring). Derive linear temperature correction factors for each analyte:

Corrected_Concentration = Raw_Concentration * (1 + Kt * (T_measured - T_reference))

Store the temperature coefficient Kt for each analyte in NVS.

### 7.2 Daily Quality Control

1. At the start of each operating day, the operator inserts a provided QC calibration strip with known analyte values.
2. The device runs a standard measurement cycle and compares the results against the expected values stored in firmware.
3. If all 10 parameters fall within +/- 10% of expected values, the QC passes and normal operation is enabled.
4. If any parameter deviates more than 10%, the OLED displays a QC FAIL warning and prompts the operator to run a field recalibration.
5. QC results (pass/fail, deviations for each parameter) are logged to the SD card with a QC flag.

### 7.3 Field Recalibration

1. The operator accesses calibration mode via the OLED menu (long-press the button for 3 seconds).
2. On-screen prompts guide insertion of calibration strips at each concentration level.
3. The firmware captures and processes each strip, then recomputes the polynomial coefficients.
4. Updated coefficients are stored in NVS, overwriting the previous values.
5. A verification pass automatically runs: the operator inserts one additional calibration strip, and the firmware confirms the new coefficients produce results within specification.

## 8. Regulatory Considerations for India (CDSCO / MDR 2017)

### 8.1 Device Classification

Under India's Medical Devices Rules, 2017 (MDR 2017), administered by the Central Drugs Standard Control Organization (CDSCO), this device is classified as a Class B In-Vitro Diagnostic (IVD) Medical Device (moderate risk). The classification is based on:

- The device performs in-vitro analysis of human biological specimens (urine).
- Results are used for screening and monitoring, not as sole confirmatory diagnostic evidence.
- The device does not involve invasive contact with the patient.
- Urine dipstick analyzers are explicitly categorized under moderate-risk IVD devices in the CDSCO classification guidelines.

### 8.2 Registration Process

Step 1: Manufacturing License (Form MD-1)

- Applicant: The manufacturing entity (company or individual).
- Authority: State Drug Licensing Authority of the state where the manufacturing facility is located.
- Requirements: GMP-compliant manufacturing facility, qualified technical staff, documented manufacturing process, quality control laboratory.
- Fee: INR 5,000 -- 10,000 (approximately USD 60 -- 120).
- Timeline: 2 -- 3 months from application to issuance.

Step 2: Product Registration (Form MD-6)

- Authority: CDSCO, New Delhi (online submission via the SUGAM portal).
- Required Documentation:
- Device Master File (description, intended use, specifications)
- Technical documentation (design files, schematics, firmware description)
- Risk analysis per ISO 14971 (FMEA, hazard analysis, risk mitigation)
- Performance evaluation data (analytical sensitivity, specificity, precision, accuracy studies comparing against a predicate device)
- Clinical evidence or literature review demonstrating clinical validity of urine dipstick analysis
- QMS certificate (ISO 13485:2016)
- Labeling and Instructions for Use (IFU) drafts
- Declaration of conformity
- Fee: INR 10,000 -- 50,000 (approximately USD 120 -- 600), depending on device sub-class.
- Timeline: 6 -- 12 months. CDSCO may request additional data or clarification, which can extend the timeline.

Step 3: Quality Management System Certification

- Standard: ISO 13485:2016 (Medical Devices -- Quality Management Systems)
- Certification Bodies: TUV SUD, BSI, SGS, or Bureau Veritas (must be accredited notified bodies).
- Cost: USD 5,000 -- 15,000 for initial certification audit, plus annual surveillance audit fees (USD 2,000 -- 5,000).
- Scope: Covers design controls, document management, supplier management, production controls, CAPA, and post-market surveillance.

### 8.3 Standards Compliance

The following standards apply to the design, manufacture, and testing of this device:

Standard | Title | Applicability
IEC 61010-1 | Safety for electrical equipment for measurement, control, and laboratory use | General safety requirements
IEC 61010-2-101 | Particular requirements for IVD medical equipment | IVD-specific safety requirements
ISO 14971 | Application of risk management to medical devices | Risk analysis (FMEA, FTA)
IEC 62304 | Medical device software -- Software lifecycle processes | Firmware development lifecycle
ISO 13485 | Quality management systems for medical devices | Manufacturing QMS
CLSI GP16-A3 | Urinalysis -- Approved Guideline | Analytical methodology, QC requirements
IEC 62471 | Photobiological safety of lamps and lamp systems | UV-C LED safety assessment

### 8.4 Labeling Requirements (MDR 2017)

All labels, packaging, and Instructions for Use must include:

- Device name and model number
- Manufacturer name, address, and contact information
- "For In-Vitro Diagnostic Use Only" (prominently displayed)
- Batch or lot number
- Date of manufacture
- Expiry date or shelf life (if applicable to consumables)
- Storage and operating conditions (temperature, humidity)
- CDSCO registration number (after approval)
- Unique Device Identification (UDI) number
- CE or BIS mark (if applicable)
- Instructions in English and Hindi (minimum two languages)
- Caution: "UV-C radiation source -- do not operate with tray open"
- Electrical safety symbols per IEC 60417

### 8.5 Post-Market Requirements

- Adverse Event Reporting: Mandatory reporting to CDSCO within 10 days for serious incidents.
- Field Safety Corrective Actions (FSCA): Documented procedure for recalls or safety notices.
- Post-Market Surveillance: Periodic review of device performance, customer complaints, and QC data.
- Annual License Renewal: Manufacturing license must be renewed annually with the state licensing authority.

### 8.6 Market Positioning and Pricing

Competing Device | Approximate Price (INR) | Origin
Siemens Clinitek Status+ | 80,000 -- 1,20,000 | Imported (Germany)
Arkray PocketChem UA | 60,000 -- 80,000 | Imported (Japan)
Mission U120 | 35,000 -- 50,000 | Imported (China)
This Device (Target) | 15,000 -- 20,000 | Domestic (India)

The target price of INR 15,000 -- 20,000 represents a 60 -- 80% cost reduction versus imported alternatives. This is achievable due to: local manufacturing (no import duties, lower logistics costs), ESP32-based platform (low-cost MCU versus proprietary ASICs), 3D-printed or locally injection-molded enclosure (versus imported housings), and simplified optical design (single camera versus multi-LED reflectance arrays). The target market includes primary health centers (PHCs), community health centers (CHCs), diagnostic laboratories, and point-of-care clinics across rural and semi-urban India, where imported analyzers are cost-prohibitive.

End of Build Report

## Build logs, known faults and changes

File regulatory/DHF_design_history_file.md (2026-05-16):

# DESIGN HISTORY FILE (DHF)
## Urine Dipstick Analyzer — Model UDA-PROTO-001

| | |
|---|---|
| **Device Name** | Urine Dipstick Analyzer |
| **Model / Catalog No.** | UDA-PROTO-001 |
| **Classification** | Class B IVD (CDSCO MDR 2017, Third Schedule, Rule 3) |
| **Software Safety Class** | Class B (IEC 62304) |
| **Document No.** | DHF-UDA-001 |
| **Version** | 0.1 (Draft) |
| **Issue Date** | 2026-05-16 |
| **Manufacturer** | Siddhant Saboo (sole proprietor); license number TBD |
| **Manufacturing Site** | India (city TBD) |
| **Prepared by** | Siddhant Saboo, Design Lead |
| **Reviewed by** | TBD — Quality Manager (signature placeholder) |
| **Approved by** | TBD — Management Representative (signature placeholder) |

---

## 1. Purpose and Scope

This Design History File (DHF) records the design and development activities of the Urine Dipstick Analyzer (UDA-PROTO-001) in accordance with **ISO 13485:2016 clause 7.3 (Design and Development)** and the **Medical Devices Rules, 2017 (CDSCO)**. It is the master index to all design records — design inputs, outputs, reviews, verifications, validations, and changes — for the life of the device.

The DHF is a **living document**. As the device progresses from prototype to commercialised product, new evidence (test reports, review minutes, change orders) is added under controlled revision.

## 2. Design and Development Planning

### 2.1 Phases and Gate Reviews

The development of UDA-PROTO-001 follows a V-model with five gated phases. Each gate is a formal Design Review (DR-#) chaired by the Design Lead with mandatory attendance of Quality and Regulatory.

| Phase | Name | Key Activities | Output(s) | Gate |
|---|---|---|---|---|
| 0 | Concept | Market research; user persona; predicate landscape | Concept brief | DR-1 |
| 1 | Feasibility | Optical bench experiments; reagent strip compatibility study; component down-select | Feasibility report; risk-management plan v0.1 | DR-2 |
| 2 | Design | Schematic, PCB, mechanical CAD, firmware architecture, RMF, SRS | Design output dossier | DR-3 |
| 3 | Verification & Validation | Bench V&V; usability formative; pilot clinical | V&V protocols and reports; clinical evaluation report | DR-4 |
| 4 | Design Transfer | IQ/OQ/PQ; supplier qualification; pilot build | Master Device Record (MDR); manufacturing instructions | DR-5 |
| 5 | Post-Market | Surveillance, vigilance, periodic safety update | PSUR; complaint reports | n/a |

### 2.2 Roles and Responsibilities

| Role | Responsibility |
|---|---|
| Design Lead (S. Saboo) | Overall design authority; signs off design outputs |
| Software Lead | IEC 62304 deliverables, code review, SBOM |
| Quality Manager (TBD) | ISO 13485 conformance, design review minutes, CAPA |
| Regulatory Affairs (TBD) | CDSCO submission, BIS test coordination |
| Clinical Investigator (TBD) | Performance evaluation per CDSCO Sept 2022 notice |
| Manufacturing Lead (TBD) | Design transfer, supplier audits |

### 2.3 Planned Outputs per Gate

- **DR-1:** Concept brief; preliminary intended-use statement.
- **DR-2:** Feasibility report; predicate comparison v0; risk-management plan.
- **DR-3:** Frozen schematic (`urine_dipstick_analyzer.kicad_sch`), PCB (`*.kicad_pcb`), BOM (`BOM.csv`), firmware repository tag, mechanical CAD (`*.step`), IFU draft, label artwork draft, RMF, SRS, traceability matrix.
- **DR-4:** All verification reports; validation summary; clinical report; usability validation report.
- **DR-5:** Approved master records; IQ/OQ/PQ reports; first-article inspection; design transfer certificate.

## 3. Design Inputs

### 3.1 User Needs (UN-###)

Compiled from interviews with primary-care physicians, lab technicians, and a literature scan of point-of-care urinalysis workflows.

| ID | User Need |
|---|---|
| UN-001 | Device shall read a 10-pad commercial urine dipstick and report semi-quantitative results for glucose, protein, ketones, bilirubin, blood, pH, urobilinogen, nitrite, leukocytes, and specific gravity. |
| UN-002 | Time-to-result ≤ 120 seconds from strip insertion to display. |
| UN-003 | Operable by a clinical lab technician with no specialised training beyond reading the IFU. |
| UN-004 | Runs on internal rechargeable battery for ≥ 50 tests per charge. |
| UN-005 | Charges via USB-C from a standard 5 V / 1 A source. |
| UN-006 | Tolerates indoor lighting (offices, clinics, 200–1000 lux ambient). |
| UN-007 | Operates between 15 °C and 35 °C ambient. |
| UN-008 | Operates between 20% and 80% non-condensing relative humidity. |
| UN-009 | Compatible with at least three commercial reagent strip brands (Multistix, Combur-10, AUTION-Sticks). |
| UN-010 | Displays results on an integrated colour screen ≥ 2 inches. |
| UN-011 | Allows the operator to scan a patient or sample barcode and associate results with the ID. |
| UN-012 | Stores at least 1 000 historical records on internal SD card. |
| UN-013 | Exports records as CSV or JSON over USB. |
| UN-014 | Provides audible and visual alerts for completion, low battery, and errors. |
| UN-015 | Sterilises the strip tray between tests to prevent cross-contamination. |
| UN-016 | Prevents UV-C emission whenever the tray is open. |
| UN-017 | Allows the operator to recalibrate using a ColorChecker reference card without opening the enclosure. |
| UN-018 | Provides a Quality Control (QC) workflow with positive and negative control strips. |
| UN-019 | Indicates expired or incompatible strips before reading. |
| UN-020 | Retains time/date through power loss (RTC backup). |
| UN-021 | Survives a 1 m drop onto vinyl flooring without functional loss. |
| UN-022 | Cleanable with isopropyl alcohol 70% and quaternary ammonium wipes. |
| UN-023 | All patient-contacting surfaces (tray) are non-porous and disinfectable. |
| UN-024 | Audit-trail captures operator ID, timestamp, lot of reagent strip, and raw result. |

### 3.2 Regulatory and Standards Inputs

| Input | Source | Applicability |
|---|---|---|
| Medical Devices Rules, 2017 (MDR-2017) | CDSCO, India | Class B IVD; Form MD-3 manufacturing licence |
| ISO 13485:2016 | International | Quality Management System |
| ISO 14971:2019 | International | Risk management |
| IEC 62304:2006 / A1:2015 | International | Software lifecycle (Class B) |
| IEC 61010-1:2010+A1:2019 | International / BIS adoption | General safety, electrical equipment for laboratory use |
| IEC 61010-2-101:2018 | International | Particular requirements for IVD medical equipment |
| IEC 62366-1:2015 | International | Usability engineering |
| IEC 60601-1-2:2014 (4th ed.) | International | EMC for medical electrical equipment |
| ISO 15223-1:2021 | International | Symbols for medical device labels |
| CLSI GP16-A3 | CLSI (USA) | Urinalysis good practice guideline |
| ISO 10993-1:2018 | International | Biocompatibility (surface contact, brief duration) |
| WEEE / E-Waste (Management) Rules 2022 | MoEF&CC, India | End-of-life disposal of electronics |
| AERB GSR Part-3 | AERB India | (Non-applicable — no ionising radiation; UV-C only) |

### 3.3 Performance Inputs (Targets)

Derived from predicate device performance and intended-use claims. Acceptance is established at design verification. These numbers are **engineering targets**; final accuracy claims will be set after V&V data.

| Parameter | Target |
|---|---|
| Glucose | ≥ 90% agreement with predicate at each semi-quantitative level (Neg, Trace, 1+, 2+, 3+, 4+) |
| Protein | ≥ 90% agreement |
| Ketones | ≥ 90% agreement |
| Bilirubin | ≥ 85% agreement (typically the noisiest pad) |
| Blood | ≥ 90% agreement |
| pH | ± 0.5 units vs. predicate |
| Urobilinogen | ≥ 85% agreement |
| Nitrite | ≥ 95% qualitative agreement |
| Leukocytes | ≥ 90% agreement |
| Specific Gravity | ± 0.005 vs. predicate |
| Time-to-result | ≤ 120 s after strip insertion |
| Repeatability | CV ≤ 10% on triplicate reads of the same dry strip |
| Battery life | ≥ 50 measurements per full charge |
| Charge time | ≤ 3 h from 0% to 100% |
| IP rating | IP22 (vertical drip protection for spill resistance) |

## 4. Design Outputs

The design outputs frozen at DR-3 are version-controlled in the repository at `/Users/siddhantsaboo/Desktop/agentic workflows/urine_dipstick_cad/`:

| Output | File(s) | Status |
|---|---|---|
| Schematic | `urine_dipstick_analyzer.kicad_sch`, `schematic_render.png` | Draft — 252 ERC violations to be cleared before freeze (see STATUS.md) |
| PCB layout | `urine_dipstick_analyzer.kicad_pcb` | Draft — 75 DRC violations, 51 unrouted nets |
| Gerbers | `gerbers.zip` | NOT manufacturable; placeholder |
| BOM | `BOM.csv`, `BOM.pdf` | Complete, 111 parts, real MPNs |
| Mechanical CAD | `*.step`, `*.stl` (enclosure, tray, mounts) | Complete |
| 2D drawings | `drawings/*.pdf` | Complete (7 sheets) |
| Firmware source | `firmware/urine_dipstick_analyzer/` | Compiles; integration of UV/heater/PID still pending |
| Calibration data | `calibration.json` | Schema valid; placeholder coefficients |
| IFU | `regulatory/IFU_instructions_for_use.md` | This dossier |
| Label artwork | `regulatory/label_artwork.md` | This dossier |
| Risk Management File | `regulatory/RMF_risk_management_iso14971.md` | This dossier |

## 5. Design Reviews

| DR # | Phase Gate | Planned Date | Attendees (target) | Output |
|---|---|---|---|---|
| DR-1 | Concept | 2025-09-15 (held informally) | Design Lead | Concept brief approved |
| DR-2 | Feasibility | 2026-01-20 (held informally) | Design Lead | Predicate comparison v0; component down-select |
| DR-3 | Design Freeze | TBD (target 2026-08-01) | Design Lead, Quality Mgr, Reg Affairs, Software Lead | Sign-off on schematic/PCB/firmware/IFU/RMF |
| DR-4 | Pre-V&V | TBD (target 2026-11-01) | All above + Clinical Investigator | Sign-off on V&V protocols and clinical plan |
| DR-5 | Pre-Transfer | TBD (target 2027-03-01) | All above + Manufacturing Lead | Approve design transfer to manufacturing |

Each review will produce minutes recording: items reviewed, findings, action items with owner and due date, and a sign-off on whether to proceed to the next phase. Minutes are stored under `regulatory/design_reviews/DR-#_minutes.pdf`.

## 6. Design Verification

Verification answers "did we build the device right?" — i.e., do the design outputs meet the design inputs? Each input ID (UN-### and performance target) is verified through one or more tests.

### Planned Verification Activities

| Test ID | Scope | Method | Acceptance |
|---|---|---|---|
| VER-01 | Strip image capture quality | Capture 50 strip images; measure pad ROI SNR | SNR ≥ 30 dB per pad |
| VER-02 | LED intensity stability | Log white-LED output over 1 h | ≤ 2% drift |
| VER-03 | Stepper repeatability | Move strip 100 times to imaging position, measure with dial gauge | ≤ 0.2 mm RMS deviation |
| VER-04 | Heater PID overshoot | Step setpoint 25 → 30 °C, log SHT31 | ≤ 1 °C overshoot, ≤ 60 s settle |
| VER-05 | UV-C interlock | Open tray during UV cycle; measure UV-C with radiometer | UV-C off within 100 ms |
| VER-06 | Battery life | Run 100 simulated cycles | ≥ 50 measurements per charge |
| VER-07 | Drop test | 1 m drop, six faces, vinyl floor | No functional loss |
| VER-08 | IP22 | Dip simulation per IEC 60529 | Pass IP22 |
| VER-09 | EMC immunity & emissions | External BIS lab | IEC 60601-1-2 ed.4 |
| VER-10 | Electrical safety | External BIS lab | IEC 61010-1, IEC 61010-2-101 |
| VER-11 | Time-to-result | Stopwatch, 30 strips | ≤ 120 s |
| VER-12 | Software unit tests | per IEC 62304 §5.5 | 100% pass on Class B critical units |
| VER-13 | Software system test | Black-box per IEC 62304 §5.7 | 100% pass on system requirements |
| VER-14 | Calibration repeatability | 10 ColorChecker captures | ΔE ≤ 3.0 between runs |
| VER-15 | Cross-contamination | UV cycle effectiveness study, RLU swab pre/post | ≥ 3 log reduction |

Verification reports are filed under `regulatory/verification/VER-##.pdf`.

## 7. Design Validation

Validation answers "did we build the right device?" — i.e., does the finished device meet the user needs in the actual use environment?

### Clinical Evaluation Plan (Summary)

| Item | Description |
|---|---|
| Objective | Demonstrate substantial equivalence in semi-quantitative analyte readings between UDA-PROTO-001 and Roche Urisys 1100 (predicate) |
| Site | One pathology lab in India (TBD) |
| Investigator | TBD |
| Sample size | 60 paired urine samples (rationale: detect ≥80% agreement at α=0.05, power 0.80) |
| Reagent strip | Roche Combur-10 (CDSCO-approved) |
| Ethics approval | Institutional Ethics Committee (IEC) approval required before enrolment |
| Acceptance | ≥ 90% category agreement for 7/10 analytes; ≥ 85% for bilirubin and urobilinogen; ± 0.5 pH; ± 0.005 SG |
| Sub-study | Inter-device variability across 3 production units of UDA-PROTO-001 |

### Usability Validation (IEC 62366-1)

A formative usability study with 5 representative users (lab tech, GP, nurse) using the IFU and prototype. Tasks: (a) unpack and set up, (b) charge, (c) calibrate, (d) run a test, (e) interpret results, (f) export data. Findings drive IFU revisions before summative validation.

## 8. Design Transfer

Design transfer occurs at DR-5 and includes:

- **Master Device Record (MDR):** consolidated drawings, BOM, software image, firmware OTA package, test specifications.
- **Manufacturing Process Instructions (MPI):** PCBA assembly, mechanical assembly, factory calibration with ColorChecker, functional test station design.
- **Supplier Qualification:**
  - Tier-1 critical: OV2640 camera, ESP32-S3, LiPo cell, UV-C LED. Each supplier subjected to supplier audit and incoming inspection plan.
  - Tier-2: passives, connectors. Inspected on lot-acceptance basis.
- **IQ/OQ/PQ Plan:**
  - **IQ (Installation Qualification):** verify factory assembly fixtures, test jigs, calibration cards.
  - **OQ (Operational Qualification):** run 3 pilot lots (10 units each) and demonstrate process capability Cpk ≥ 1.33.
  - **PQ (Performance Qualification):** 30-unit pilot lot tested against full V&V protocol with no deviations.
- **Training records** for production operators.

## 9. Design Changes

A change control SOP (`SOP-CC-001`) governs all post-freeze changes. Workflow:

1. Change request raised in change-control register with rationale.
2. Impact assessment: design inputs/outputs affected, risk-management impact, regulatory impact (does it require re-submission?).
3. Approval by Design Lead, Quality Manager, and (for risk-relevant changes) Regulatory Affairs.
4. Implementation in version-controlled outputs.
5. Re-verification and re-validation as appropriate.
6. Closure with updated traceability matrix.

Software changes additionally follow IEC 62304 §6 (Software Maintenance Process).

## 10. Post-Market Surveillance

Per **MDR-2017 Rule 89** (Post-market surveillance):

- Complaint-handling SOP (`SOP-PMS-001`) — all complaints logged, investigated, trended.
- Periodic Safety Update Reports (PSUR) annually for the first three years, then per CDSCO direction.
- Vigilance reporting: serious adverse events to CDSCO within 15 days; non-serious within 30 days.
- Field Safety Corrective Actions (FSCA) executed as required.

## 11. Traceability Matrix

Cross-reference from user need → design input → design output → verification → validation. (Abridged: top 20 needs.)

| UN | Input/Spec | Output (file) | Verification | Validation |
|---|---|---|---|---|
| UN-001 | 10-pad reading | Firmware `analysis.h`, calibration.json | VER-01, VER-14 | Clinical 60-sample |
| UN-002 | ≤120 s | Firmware main loop timing | VER-11 | Usability formative |
| UN-003 | Tech user | IFU §6, §7 | n/a | Usability summative |
| UN-004 | ≥50 tests/charge | MAX17048 fuel-gauge integration | VER-06 | Field test |
| UN-005 | USB-C 5V/1A | MCP73833 charger; BOM | Charge time bench | n/a |
| UN-006 | 200–1000 lux | BH1750 ambient compensation | VER-01 (varied lighting) | Clinical site lighting |
| UN-007 | 15–35 °C | SHT31 monitoring; heater | Environmental chamber test | n/a |
| UN-008 | 20–80% RH | SHT31 logging | Environmental chamber | n/a |
| UN-009 | 3 strip brands | Calibration tables × 3 | VER-01 per brand | Clinical sub-study |
| UN-010 | 2" colour screen | ILI9341 display | Display readability test | Usability |
| UN-011 | Barcode scan | GM65 module + firmware | Scan-rate test, 100 barcodes | Usability |
| UN-012 | 1000 records | SD storage, JSON log | Storage stress test | n/a |
| UN-013 | CSV/JSON export | Serial/USB export module | Round-trip parse test | Usability |
| UN-014 | Audible/visual alerts | Buzzer + RGB LED | Acoustic/visual bench check | Usability |
| UN-015 | UV sterilisation | UV-C LED + cycle in firmware | VER-15 (3-log reduction) | n/a |
| UN-016 | UV interlock | Reed switch + MOSFET gate | VER-05 | n/a |
| UN-017 | Recalibration | Calibration mode in firmware | VER-14 | Usability |
| UN-018 | QC workflow | QC mode in firmware | QC strip read test | Clinical sub-study |
| UN-019 | Expired strip detection | Barcode + RTC check | Expired-strip simulation | Usability |
| UN-020 | RTC backup | DS3231 + CR2032 | Power-loss test | n/a |
| UN-021 | 1 m drop | Enclosure design | VER-07 | n/a |
| UN-022 | Disinfectable | Material selection (PETG/ABS), no porous surfaces | Chemical compatibility test (IPA 70%, quat-amm) | n/a |
| UN-023 | Non-porous patient contact | Tray PETG | Visual + ISO 10993 surface category justification | n/a |
| UN-024 | Audit trail | Storage module + RTC | Log integrity test | Site auditor review |

The full machine-readable traceability matrix lives in `regulatory/traceability_matrix.xlsx` (TBD).

## 12. References

- ISO 13485:2016 — Medical devices — Quality management systems.
- ISO 14971:2019 — Medical devices — Application of risk management.
- IEC 62304:2006/A1:2015 — Medical device software — software lifecycle processes.
- IEC 61010-1:2010+A1:2019 / IEC 61010-2-101:2018.
- IEC 62366-1:2015 — Application of usability engineering.
- CDSCO, Medical Devices Rules, 2017 and subsequent amendments.
- CDSCO Notice dated 23 September 2022, *Performance evaluation of in-vitro diagnostic medical devices*.

---

*End of DHF v0.1. Next revision after DR-3 with frozen design outputs.*

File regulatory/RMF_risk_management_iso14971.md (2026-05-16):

# RISK MANAGEMENT FILE (RMF) — ISO 14971:2019
## Urine Dipstick Analyzer — Model UDA-PROTO-001

| | |
|---|---|
| **Document No.** | RMF-UDA-001 |
| **Version** | 0.1 (Draft) |
| **Date** | 2026-05-16 |
| **Author** | Siddhant Saboo, Design Lead |
| **Reviewer / Approver** | TBD — Quality Manager, TBD — Management Representative |
| **Applicable Standard** | ISO 14971:2019 (with ISO TR 24971:2020 guidance) |

---

## 1. Scope and Risk Management Plan

### 1.1 Scope

This Risk Management File covers the **Urine Dipstick Analyzer UDA-PROTO-001** throughout its entire lifecycle: design, manufacturing, distribution, clinical use, servicing, and disposal. The device is a **Class B in vitro diagnostic** intended for the semi-quantitative measurement of 10 urinalysis analytes from commercial reagent strips.

### 1.2 Risk Management Policy

The manufacturer commits to:

1. Identifying all reasonably foreseeable hazards associated with the device.
2. Estimating and evaluating the risks associated with each hazard.
3. Controlling those risks using the hierarchy of control defined in ISO 14971 §7:
   - (a) inherently safe design,
   - (b) protective measures in the device or manufacturing,
   - (c) information for safety (labelling, IFU, training).
4. Monitoring effectiveness of controls in production and post-production.
5. Maintaining an overall residual risk **As Low As Reasonably Practicable (ALARP)** and acceptable in light of the benefit to the patient.

### 1.3 Risk Acceptability Criteria

A **5 × 5 risk matrix** is used. Severity and probability are categorical scales:

| **Severity** | Description |
|---|---|
| S1 — Negligible | Minor inconvenience; no health impact |
| S2 — Minor | Temporary discomfort; resolved without intervention |
| S3 — Serious | Requires clinical intervention; reversible injury |
| S4 — Critical | Permanent impairment or significant misdiagnosis with delayed treatment |
| S5 — Catastrophic | Death or permanent disability |

| **Probability** | Description | Quantitative guide (per 10⁶ uses) |
|---|---|---|
| P1 — Improbable | Practically impossible | < 1 |
| P2 — Remote | Unlikely but possible | 1 – 100 |
| P3 — Occasional | May happen occasionally | 100 – 10 000 |
| P4 — Probable | Will happen several times in life of device | 10⁴ – 10⁶ |
| P5 — Frequent | Will happen often | > 10⁶ (i.e., routinely) |

### 1.4 Risk Acceptance Matrix

|  | **P1** | **P2** | **P3** | **P4** | **P5** |
|---|---|---|---|---|---|
| **S1** | Acc | Acc | Acc | Acc | ALARP |
| **S2** | Acc | Acc | Acc | ALARP | Unacc |
| **S3** | Acc | Acc | ALARP | Unacc | Unacc |
| **S4** | Acc | ALARP | Unacc | Unacc | Unacc |
| **S5** | ALARP | Unacc | Unacc | Unacc | Unacc |

- **Acc** = Acceptable, no further action required beyond standard documentation.
- **ALARP** = Acceptable only if risk has been reduced as low as reasonably practicable and the residual risk is justified by benefit.
- **Unacc** = Unacceptable; further risk control is mandatory.

---

## 2. Intended Use and Reasonably Foreseeable Misuse

### 2.1 Intended Use Statement

> The Urine Dipstick Analyzer UDA-PROTO-001 is a battery-operated, table-top in vitro diagnostic device intended for the **semi-quantitative measurement of 10 analytes** (glucose, protein, ketones, bilirubin, blood, pH, urobilinogen, nitrite, leukocytes, specific gravity) from **commercial reagent test strips dipped in human urine**. The device is intended for use by a clinical lab technician, general practitioner, or trained healthcare worker, in a clinic or laboratory environment, on adult and paediatric (≥ 2 years) patients. Results are intended to support — not replace — the clinician's diagnostic judgement.

### 2.2 Reasonably Foreseeable Misuse

| ID | Misuse | Mitigation strategy summary |
|---|---|---|
| MU-1 | Operator uses an expired or wrong-brand strip | Barcode scan + IFU warning |
| MU-2 | Operator reads result before recommended reaction time | Firmware enforces timer |
| MU-3 | Operator places the device in direct sunlight | BH1750 ambient light check; IFU warning |
| MU-4 | Operator drops the device into a urine specimen | IP22 rating; IFU warning |
| MU-5 | Operator opens the chamber during UV cycle | Reed-switch interlock |
| MU-6 | Patient self-tests at home using device | Out of scope; IFU "for professional use only" |
| MU-7 | Operator reuses a single-use strip | Barcode + visual recognition of wet pad |
| MU-8 | Use to test fluids other than urine | IFU contraindication; mechanical strip-only tray |
| MU-9 | Operator ignores low-battery warning, leading to mid-test power loss | RTC + storage; on-resume, the in-progress test is invalidated |

---

## 3. Characteristics Related to Safety (ISO 14971:2019 Annex C / ISO TR 24971 Annex A)

Answers to the standard's prompt questions:

| # | Question | Answer |
|---|---|---|
| C1 | Intended use, intended user, patient population | Professional use; lab tech / GP / clinic; adults and paediatric ≥ 2 yr |
| C2 | Is it intended to be implanted? | No |
| C3 | Is it intended to be in contact with the patient or other persons? | Only indirectly; operator hand contact with enclosure, no direct patient skin contact |
| C4 | Materials/components used; biocompatibility | PETG enclosure, ABS base, silicone gasket, EPDM foam, polyimide heater film. No direct patient contact; ISO 10993-1 surface-contact category not strictly required. Justification documented. |
| C5 | Energy delivered to or extracted from the patient | None directly; UV-C contained internally (Hazard H-3) |
| C6 | Substances delivered to or extracted from the patient | None |
| C7 | Biological materials processed | Urine specimen on the reagent strip (biohazard handling) |
| C8 | Sterile or microbiological state required? | Non-sterile device; tray cleaned with UV-C between uses |
| C9 | Routine measurement of the device | RTC, software self-test on boot |
| C10 | Is software used? | Yes — IEC 62304 Class B (see SDLC document) |
| C11 | Restricted shelf life | Battery (2-year nominal); UV-C LED (1000 h operational); reagent strips have own expiry |
| C12 | Are there delayed/long-term use effects? | No |
| C13 | Mechanical forces to which device is subjected | Bench drop (1 m); strip tray actuation |
| C14 | Determined by user input or affected by environmental factors? | Ambient light, temperature, humidity (compensated by sensors) |
| C15 | Critical or essential outputs | Analyte reading on display |
| C16 | Intended to be reusable? | Yes, multiple uses; reagent strip is single-use |
| C17 | Disposable components? | Reagent strip (consumable), battery (after life) |
| C18 | Installation or operator setup required? | Yes — initial calibration with ColorChecker card |
| C19 | Maintenance / calibration | Annual recalibration recommended; software OTA updates |
| C20 | Medical devices interaction? | None |
| C21 | Unintended outputs of energy or substances? | UV-C leakage if interlock fails (mitigated) |
| C22 | Susceptibility to environmental influences? | EMC: per IEC 60601-1-2 |
| C23 | Does it influence the environment? | E-waste / WEEE applicable at disposal |
| C24 | Essential performance? | Analyte reading accuracy ≥ 90% category agreement with predicate |
| C25 | Single-fault safety? | Critical safety functions (UV interlock, charger fault, thermal runaway) designed to fail safe |

---

## 4. Hazard Identification

Hazards are organised by source.

| ID | Source | Hazard | Hazardous Situation | Potential Harm |
|---|---|---|---|---|
| H-01 | Electrical | LiPo battery thermal runaway | Battery overheats, vents | Burn, fire |
| H-02 | Electrical | USB-C charger over-voltage | Excess voltage into charger IC | Component damage, fire |
| H-03 | Electrical | Mains-derived leakage current | User touches enclosure while charging | Microshock |
| H-04 | Electrical | Reverse polarity from non-compliant USB-C charger | Charger feeds reverse current | Battery damage |
| H-05 | Optical | UV-C leakage through tray gap | Operator's eye exposed | Photokeratitis, retinal injury |
| H-06 | Optical | White LED inadvertent direct view | Operator stares at LED at close range | Glare; minor; no retinal injury at this power |
| H-07 | Mechanical | Stepper-driven tray pinches finger | User holds tray while motor activates | Pinch injury |
| H-08 | Mechanical | Sharp edge on enclosure | User runs finger over un-deburred seam | Cut |
| H-09 | Mechanical | Drop hazard if pushed off bench | Device falls 1 m | Functional damage, bystander toe injury |
| H-10 | Biological | Urine contamination of operator hands | Splash during strip handling | Biological exposure |
| H-11 | Biological | Cross-contamination strip-to-strip | Previous urine residue on tray | False positive on next test |
| H-12 | Biological | Allergic reaction to enclosure plastic | Sensitised user touches PETG | Contact dermatitis |
| H-13 | Software | Incorrect analyte result due to algorithm bug | Display shows wrong value | Misdiagnosis, delayed treatment |
| H-14 | Software | Missed alert (silent failure mode) | Device unable to read but reports OK | Misdiagnosis |
| H-15 | Software | Calibration data corruption | Bad coefficients applied | All results biased |
| H-16 | Software | Firmware update bricks device | OTA failure | Loss of use; not safety-critical |
| H-17 | Software | Data integrity loss | SD corruption loses patient records | Audit failure |
| H-18 | Use-error | Wrong strip brand inserted | Calibration mismatch | Wrong result |
| H-19 | Use-error | Expired strip used | Reagent degraded | Wrong result |
| H-20 | Use-error | Wet/moist hands contact charger port | Splash into USB | Charger fault |
| H-21 | Use-error | Operator places device in direct sunlight | Image saturation | Wrong result |
| H-22 | Use-error | Operator obscures ambient sensor | BH1750 reading false-low | Wrong result |
| H-23 | Environmental | High humidity causes condensation in chamber | Optics fogged | Wrong result |
| H-24 | Environmental | EMC: radio (e.g., cellphone) corrupts I2C | Sensor read fails | Error or wrong result |
| H-25 | Environmental | Temperature out-of-range (cold storage) | Battery + plastics out of spec | Functional failure |
| H-26 | Environmental | Strong static discharge from operator | ESD into button or USB port | Component damage |
| H-27 | Disposal | LiPo cell discarded in regular waste | Cell punctured at landfill | Environmental fire |
| H-28 | Service | Operator opens enclosure | Exposes battery and high-current rails | Burn / shock |

---

## 5. Risk Estimation (Pre-Control)

| ID | Severity | Probability | Score (S×P) | Pre-Control Acceptability |
|---|---|---|---|---|
| H-01 | S4 | P3 | 12 | Unacc |
| H-02 | S3 | P3 | 9 | ALARP |
| H-03 | S3 | P2 | 6 | Acc |
| H-04 | S2 | P3 | 6 | Acc |
| H-05 | S4 | P3 | 12 | Unacc |
| H-06 | S2 | P3 | 6 | Acc |
| H-07 | S2 | P3 | 6 | Acc |
| H-08 | S2 | P2 | 4 | Acc |
| H-09 | S2 | P3 | 6 | Acc |
| H-10 | S3 | P4 | 12 | Unacc |
| H-11 | S4 | P4 | 16 | Unacc |
| H-12 | S2 | P2 | 4 | Acc |
| H-13 | S4 | P3 | 12 | Unacc |
| H-14 | S4 | P3 | 12 | Unacc |
| H-15 | S4 | P2 | 8 | ALARP |
| H-16 | S1 | P3 | 3 | Acc |
| H-17 | S2 | P3 | 6 | Acc |
| H-18 | S3 | P4 | 12 | Unacc |
| H-19 | S3 | P4 | 12 | Unacc |
| H-20 | S2 | P3 | 6 | Acc |
| H-21 | S3 | P3 | 9 | ALARP |
| H-22 | S3 | P3 | 9 | ALARP |
| H-23 | S3 | P3 | 9 | ALARP |
| H-24 | S3 | P3 | 9 | ALARP |
| H-25 | S2 | P3 | 6 | Acc |
| H-26 | S2 | P3 | 6 | Acc |
| H-27 | S2 | P3 | 6 | Acc |
| H-28 | S3 | P2 | 6 | Acc |

---

## 6. Risk Control Measures

Every **Unacceptable** and **ALARP** risk is reduced. For each, the control type (per ISO 14971 §7.1) and residual estimate are recorded. Verification refers to V&V tests in the DHF.

| ID | Control Type | Control Measure | Post-Control S × P | Verification |
|---|---|---|---|---|
| H-01 | (a) Inherent + (b) Protective | LiPo cell with internal PTC + MAX17048 fuel gauge + MCP73833 charger with thermal regulation; PCB-level 500 mA PTC fuse; enclosure ventilation; firmware monitors SHT31 chamber temp and shuts down ≥ 60 °C | S4 × P1 = 4 (Acc) | UN 38.3, cell datasheet; bench short-circuit test |
| H-02 | (a) Inherent | MCP73833 supports up to 7 V input absolute max; USB-C breakout exposes only 5 V; PCB-level TVS diode | S3 × P1 = 3 (Acc) | Over-voltage injection test up to 9 V |
| H-03 | (b) Protective | Plastic enclosure; only SELV inside; isolation by USB-C-rated wall adapter (user-supplied) | S3 × P1 = 3 (Acc) | IEC 61010-1 dielectric test |
| H-04 | (a) Inherent | USB-C polarity by design; charger IC has reverse-blocking | S2 × P1 = 2 (Acc) | Reverse-polarity injection |
| H-05 | (b) Protective + (c) Info | (i) MC-38 reed-switch + IRLZ44N MOSFET in **series with UV-C LED supply** — opening the tray opens the gate; (ii) EPDM foam gasket at tray seam; (iii) UV-on indicator on display + buzzer; (iv) IFU UV warning | S4 × P1 = 4 (Acc) | VER-05 with UV-C radiometer; firmware FMEA on interlock |
| H-06 | (c) Info | IFU warns not to stare at LED during reading | S2 × P2 = 4 (Acc) | IFU review |
| H-07 | (a) Inherent + (c) Info | NEMA17 20 mm body provides limited torque (0.13 Nm); tray gap < 3 mm closed → finger cannot enter; IFU warning | S2 × P1 = 2 (Acc) | Mechanical pinch-gap test |
| H-08 | (a) Inherent | Enclosure design: all external edges ≥ 1 mm radius; injection-mould inspection | S2 × P1 = 2 (Acc) | First-article inspection |
| H-09 | (b) Protective | 1 m drop survival design; rubber feet | S2 × P2 = 4 (Acc) | VER-07 |
| H-10 | (c) Info + (b) Protective | IFU mandates gloves; tray catches drips into removable channel; IPA 70% wipe-down between tests | S3 × P2 = 6 (Acc) | IFU review; tray cleanability test |
| H-11 | (b) Protective + (a) Inherent | UV-C 30-s sterilisation between tests + non-porous PETG tray + IFU 70% IPA wipe; firmware enforces UV before next strip allowed | S4 × P2 = 8 (ALARP) — justified by benefit; further reduction not practicable without disposable tray | VER-15 (≥ 3-log reduction) |
| H-12 | (a) Inherent + (c) Info | PETG and ABS are widely-used skin-contact-safe plastics; IFU lists materials so sensitised users can opt out | S2 × P1 = 2 (Acc) | Material certificate; ISO 10993-1 surface category justification |
| H-13 | (b) Protective | IEC 62304 Class B software lifecycle; code review; unit tests; algorithm validation against ColorChecker; clinical validation 60 paired samples | S4 × P1 = 4 (Acc) | VER-12, VER-13; clinical report |
| H-14 | (b) Protective | Software watchdog timer; per-step health checks; if any sensor fails firmware shows error and refuses to display result | S4 × P1 = 4 (Acc) | Fault-injection test |
| H-15 | (b) Protective | Calibration file stored with SHA-256 hash; firmware refuses to operate on mismatch | S4 × P1 = 4 (Acc) | Cal-corruption injection test |
| H-16 | (b) Protective | A/B firmware partitions with rollback; OTA failure reverts to last-known-good | S1 × P2 = 2 (Acc) | OTA fault-injection test |
| H-17 | (b) Protective | Wear-levelled writes; CRC32 per record; periodic flush | S2 × P2 = 4 (Acc) | SD pull-during-write test |
| H-18 | (b) Protective + (c) Info | GM65 barcode scanner reads strip vial label; firmware whitelists supported brands; warns operator if unknown | S3 × P2 = 6 (Acc) | Unknown-strip simulation |
| H-19 | (b) Protective + (c) Info | Barcode includes expiry date; firmware refuses to read expired strip; IFU warning | S3 × P1 = 3 (Acc) | Expired-strip simulation |
| H-20 | (c) Info | IFU instructs dry hands and dry surfaces around USB port | S2 × P2 = 4 (Acc) | IFU review |
| H-21 | (b) Protective | BH1750 ambient sensor; firmware blocks reading if > 5 lux ambient at imaging position; IFU warns about direct sunlight | S3 × P1 = 3 (Acc) | VER-01 varied lighting |
| H-22 | (b) Protective | BH1750 placed where the user is unlikely to cover it; firmware sanity-checks reading; tray geometry shields sensor | S3 × P2 = 6 (Acc) | Obstruction test |
| H-23 | (b) Protective + (c) Info | SHT31 detects RH > 80%; firmware warns; chamber fan + heater raise dewpoint margin; IFU storage RH 20–80% | S3 × P2 = 6 (Acc) | Environmental chamber |
| H-24 | (b) Protective | IEC 60601-1-2 ed.4 EMC testing; I2C with pull-ups and shielded cable; firmware retries on CRC error | S3 × P2 = 6 (Acc) | VER-09 |
| H-25 | (c) Info | IFU storage spec 5–40 °C; operate 15–35 °C; firmware refuses to operate below 10 °C | S2 × P1 = 2 (Acc) | Cold-start test |
| H-26 | (b) Protective | ESD diodes at USB port and exposed button; PCB has ground plane | S2 × P1 = 2 (Acc) | IEC 61000-4-2 air/contact discharge |
| H-27 | (c) Info | IFU + label: WEEE crossed-bin symbol; instructions to return cell to authorised e-waste vendor | S2 × P1 = 2 (Acc) | Label inspection |
| H-28 | (c) Info + (a) Inherent | Enclosure secured with M3 inserts requiring tool; service-only access labelled inside; no user-replaceable parts | S3 × P1 = 3 (Acc) | Label inspection |

---

## 7. Risk-Benefit Analysis (for ALARP-residual items)

**H-11 (cross-contamination):** Residual risk S4 × P2 = 8 (ALARP). Further reduction would require a single-use disposable tray, which would significantly increase per-test cost (≈ ₹40/test) and waste, contrary to the device's value proposition for low-resource settings. The 30-second 275 nm UV-C cycle is documented in literature to provide ≥ 3-log microbial reduction on non-porous surfaces. The IFU additionally mandates 70% IPA wipe between tests. Benefit (point-of-care urinalysis access in primary care, where the predicate Roche Urisys 1100 at ₹1.2 lakh is unaffordable) substantially outweighs the residual risk. **Accepted.**

---

## 8. Overall Residual Risk Evaluation

After applying the controls in §6, **no individual residual risk falls in the Unacceptable zone**. One residual risk (H-11) is in ALARP and is justified by the risk-benefit narrative above. All other residuals are Acceptable.

**Conclusion:** The overall residual risk of UDA-PROTO-001 is judged **acceptable** in relation to the benefits of providing rapid, low-cost semi-quantitative urinalysis to primary care.

---

## 9. Production and Post-Production Information

### 9.1 Production Controls

- Incoming inspection of safety-critical components (LiPo cell, UV-C LED, charger IC, MOSFETs) per defined sampling plan.
- 100% functional test at end-of-line: (a) UV interlock; (b) battery charge cycle; (c) full strip-read calibration check.
- Lot-by-lot retention sample.

### 9.2 Post-Production Surveillance

- **Complaint handling:** SOP-PMS-001. All complaints logged within 24 h; investigated and trended monthly.
- **Vigilance reporting** per MDR-2017 Rule 89: serious adverse events to CDSCO within 15 days, others within 30 days.
- **Periodic review:** RMF reviewed annually and after any of: (i) post-market complaint trend, (ii) design change, (iii) new standard release, (iv) field safety corrective action.
- **Inputs to review:** complaints, returns, social-media monitoring, literature scan, supplier change notices, SOUP CVE feeds.

---

## 10. References

- ISO 14971:2019 — Application of risk management to medical devices.
- ISO/TR 24971:2020 — Guidance on the application of ISO 14971.
- IEC 62366-1:2015 — Usability engineering.
- CDSCO MDR 2017, Rule 89 (Post-market surveillance) and Schedule G (label content).
- *Urine reagent strip cross-contamination and UV-C decontamination* — internal literature review (TBD).

---

*End of RMF v0.1. Next revision at DR-3.*

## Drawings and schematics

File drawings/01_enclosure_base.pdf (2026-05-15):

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

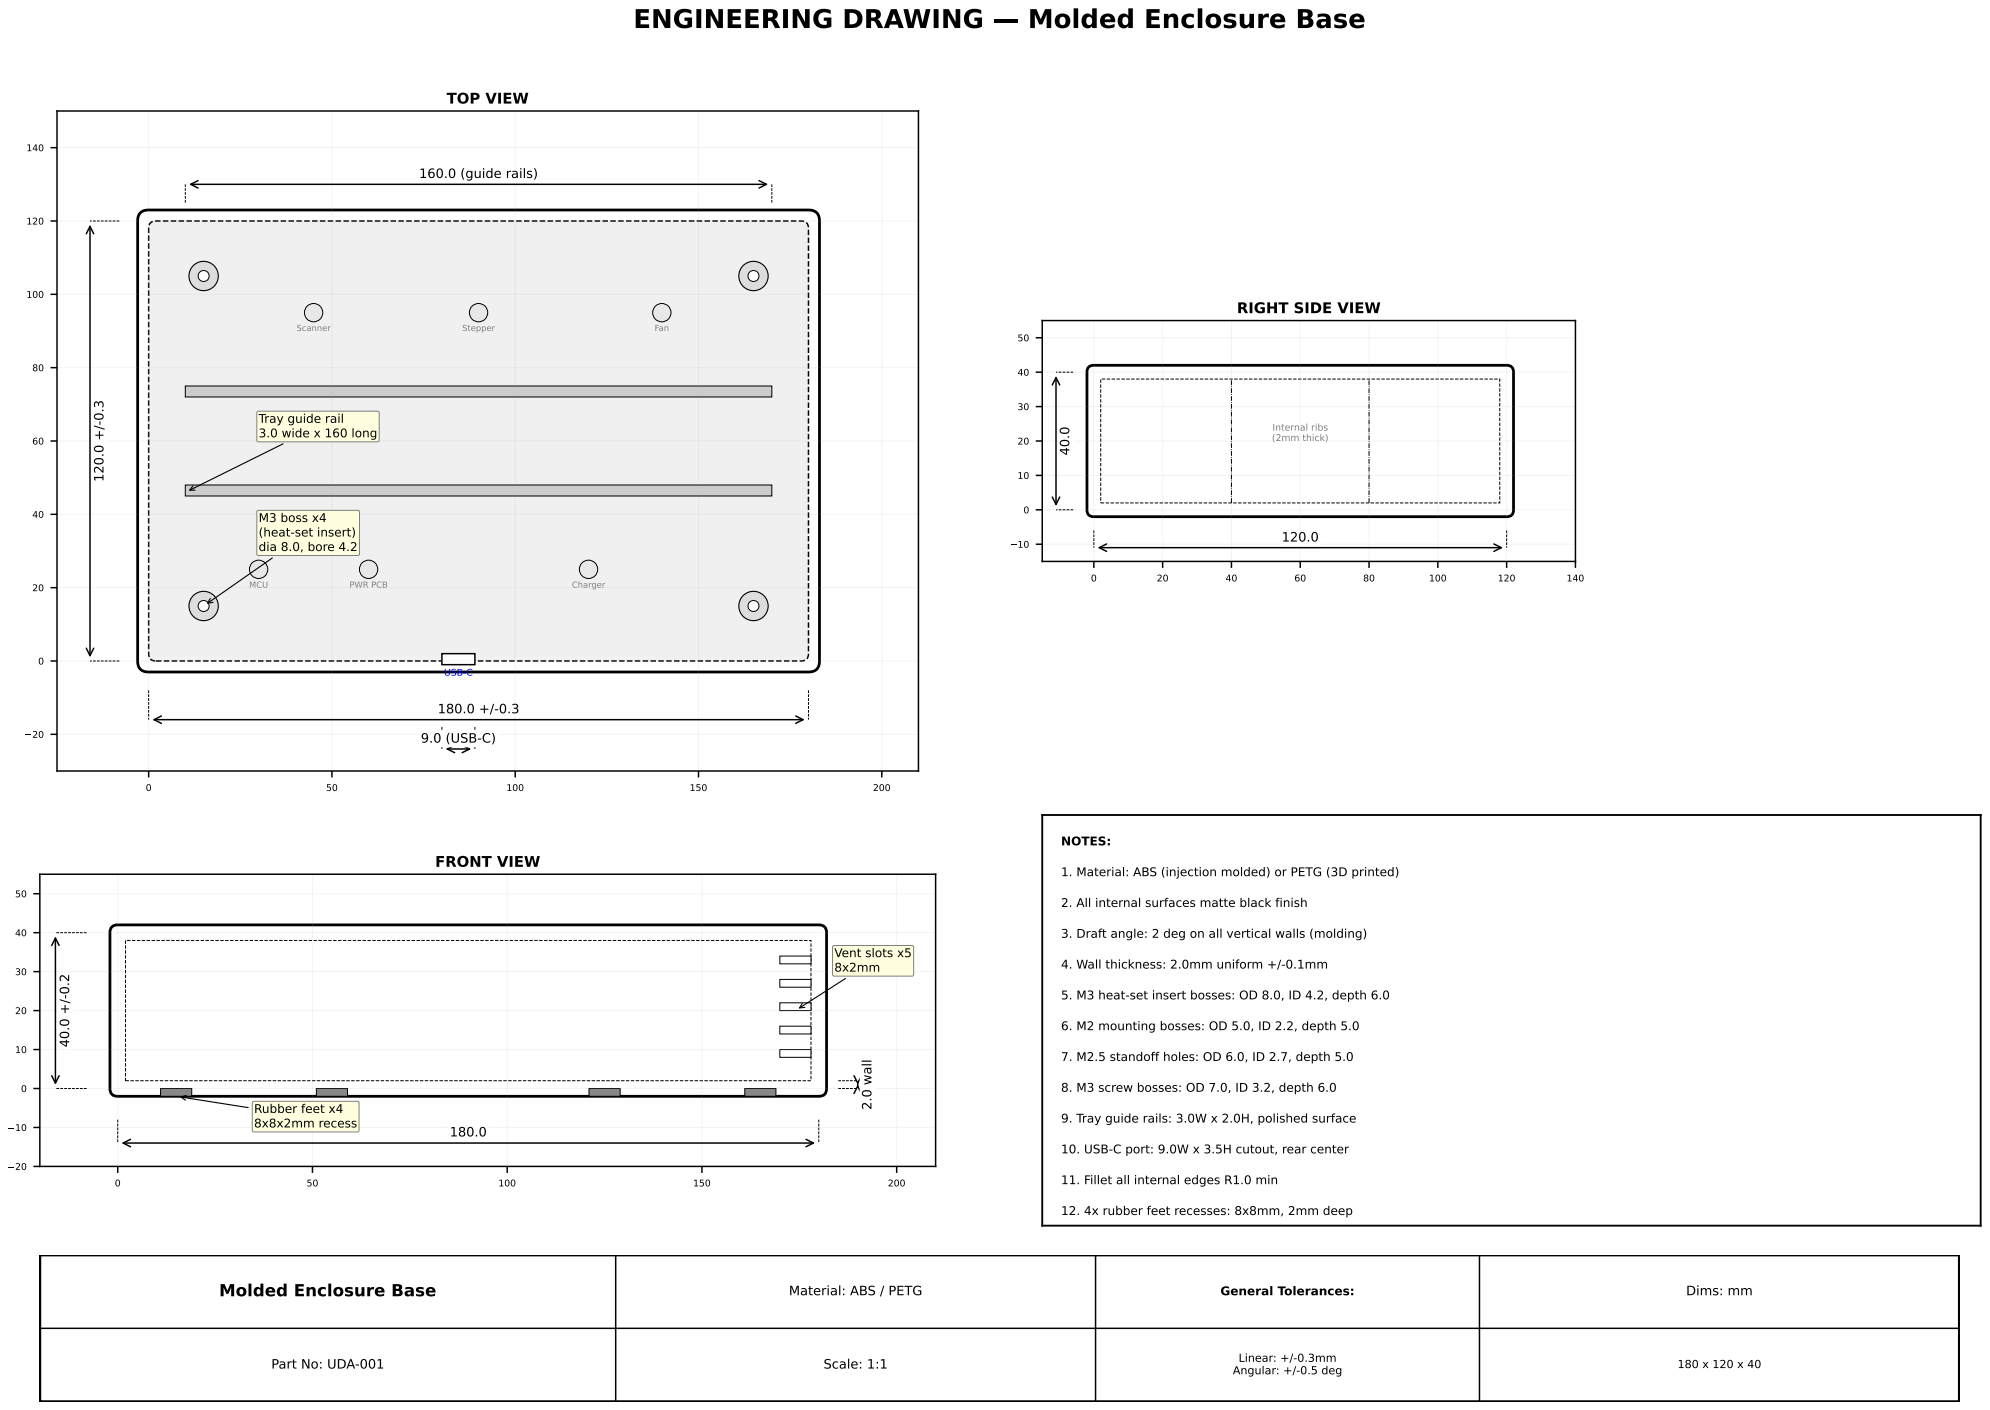
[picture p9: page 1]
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

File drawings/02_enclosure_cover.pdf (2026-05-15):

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

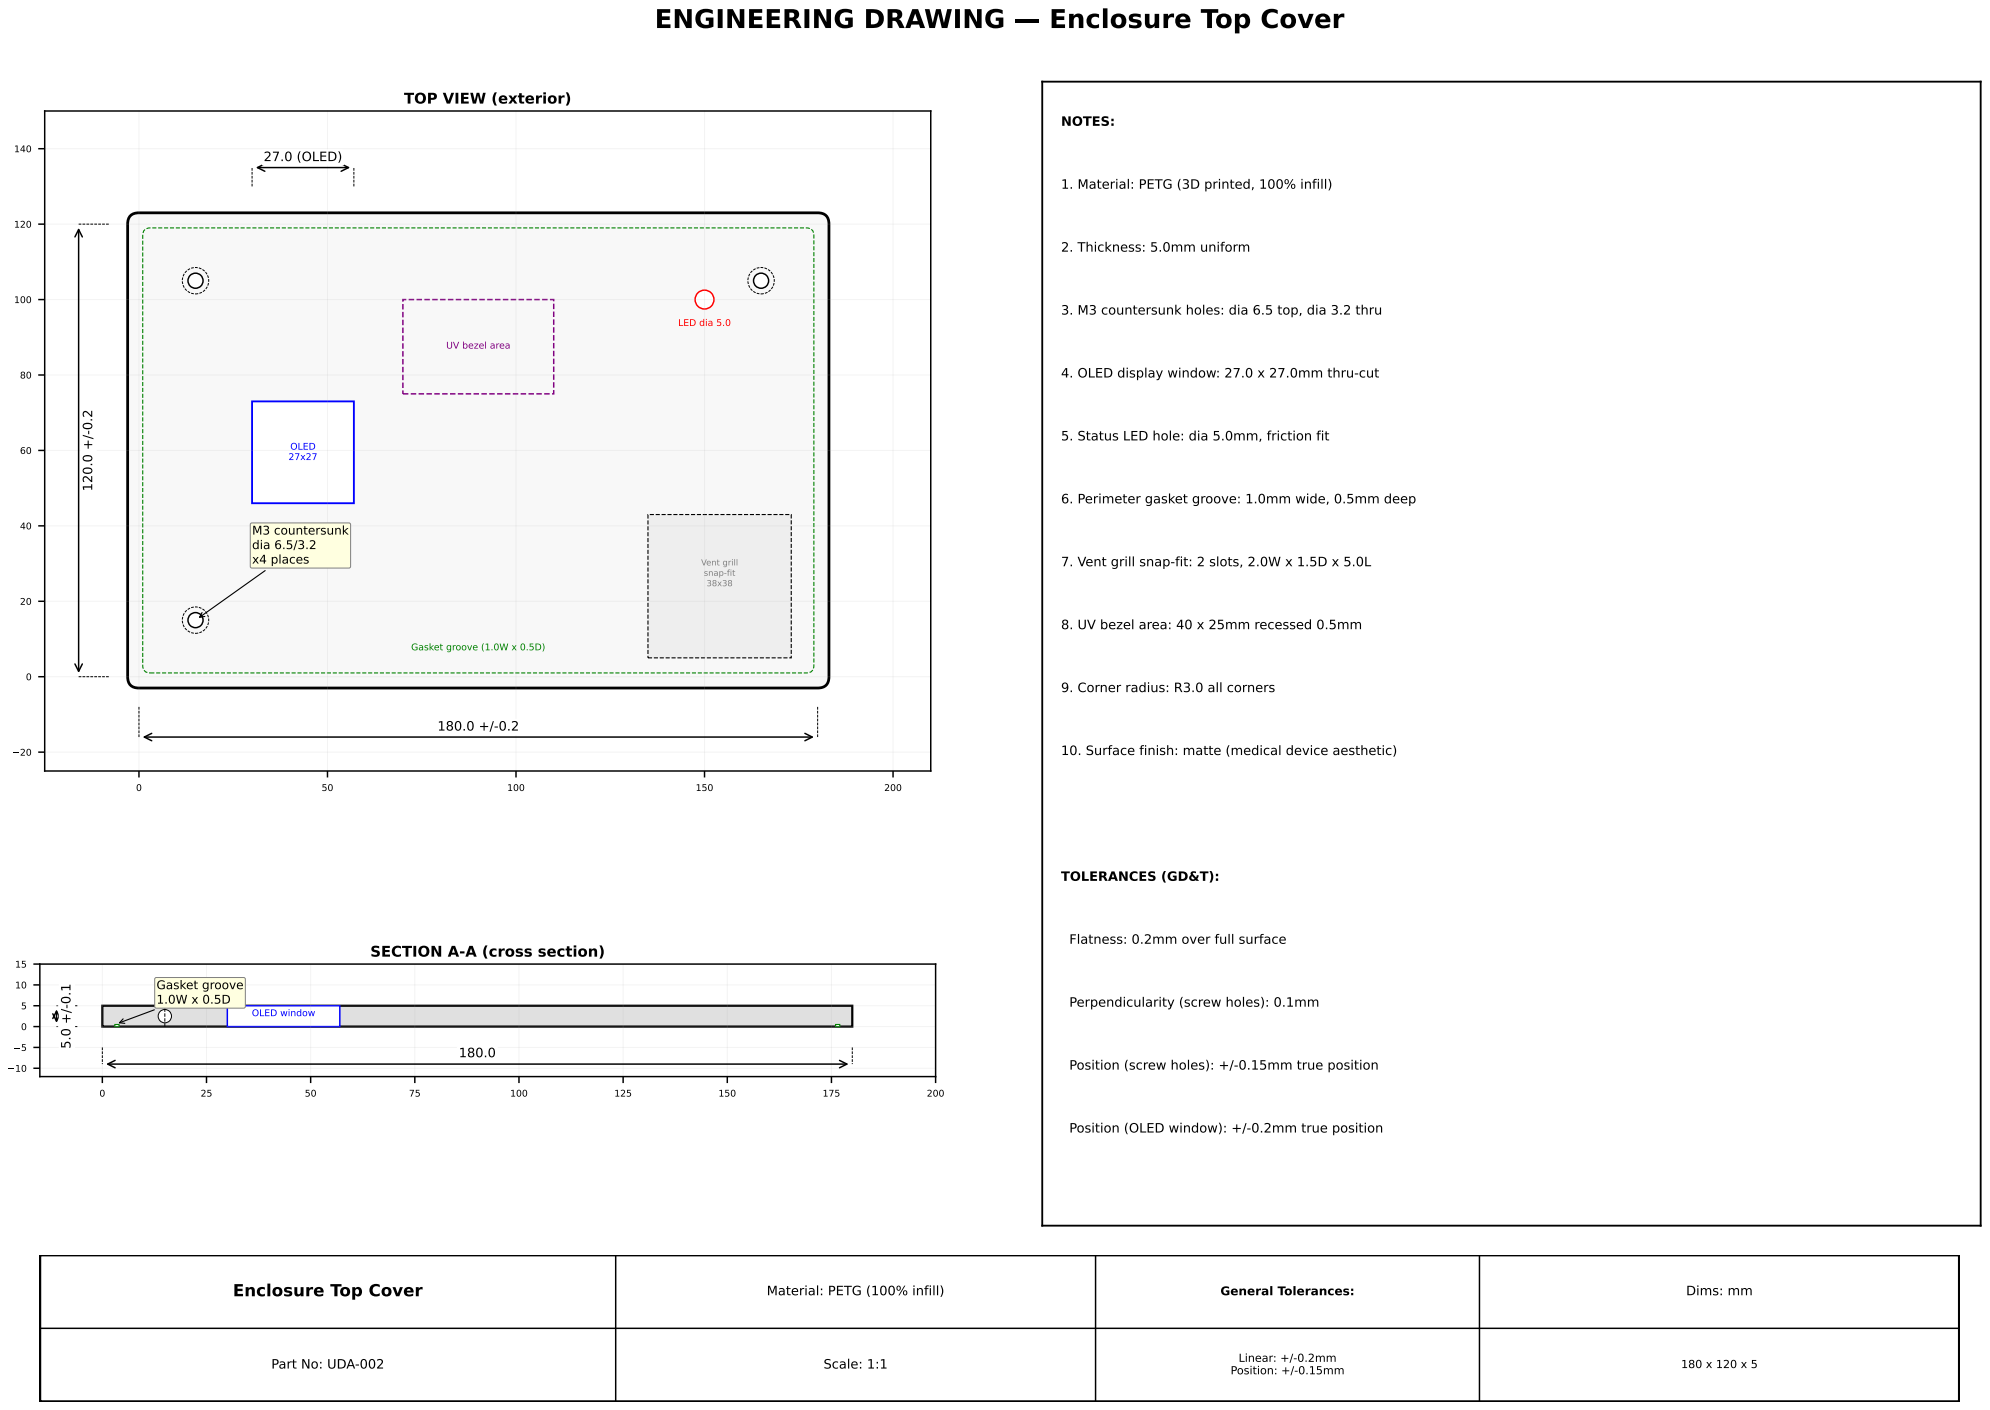
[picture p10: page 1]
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

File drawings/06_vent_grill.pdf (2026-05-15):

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

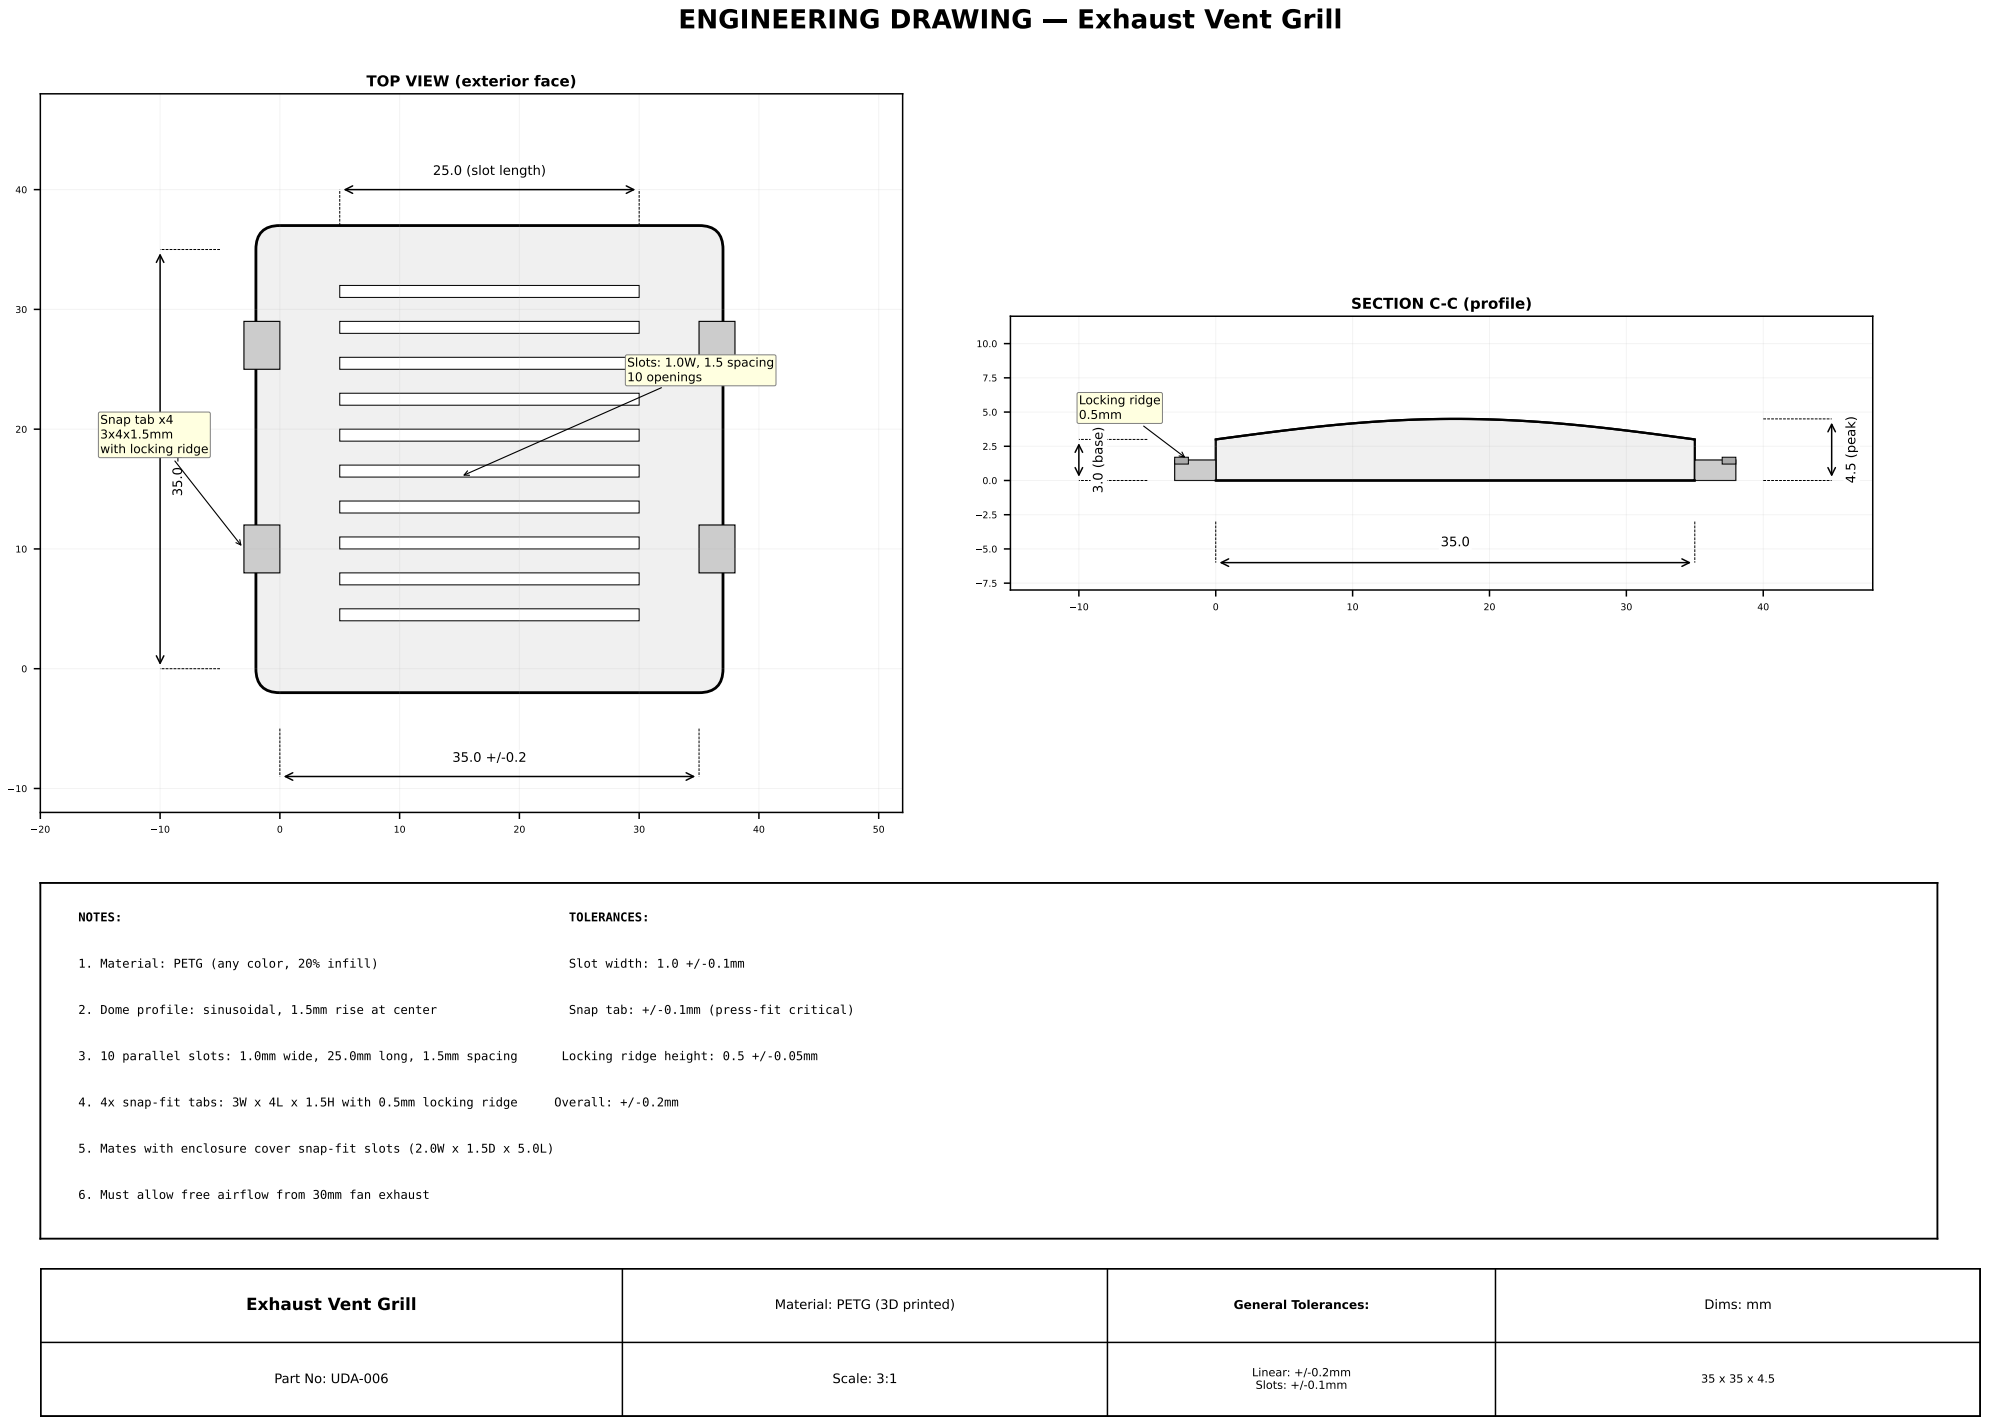
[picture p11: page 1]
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

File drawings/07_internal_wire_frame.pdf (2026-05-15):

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

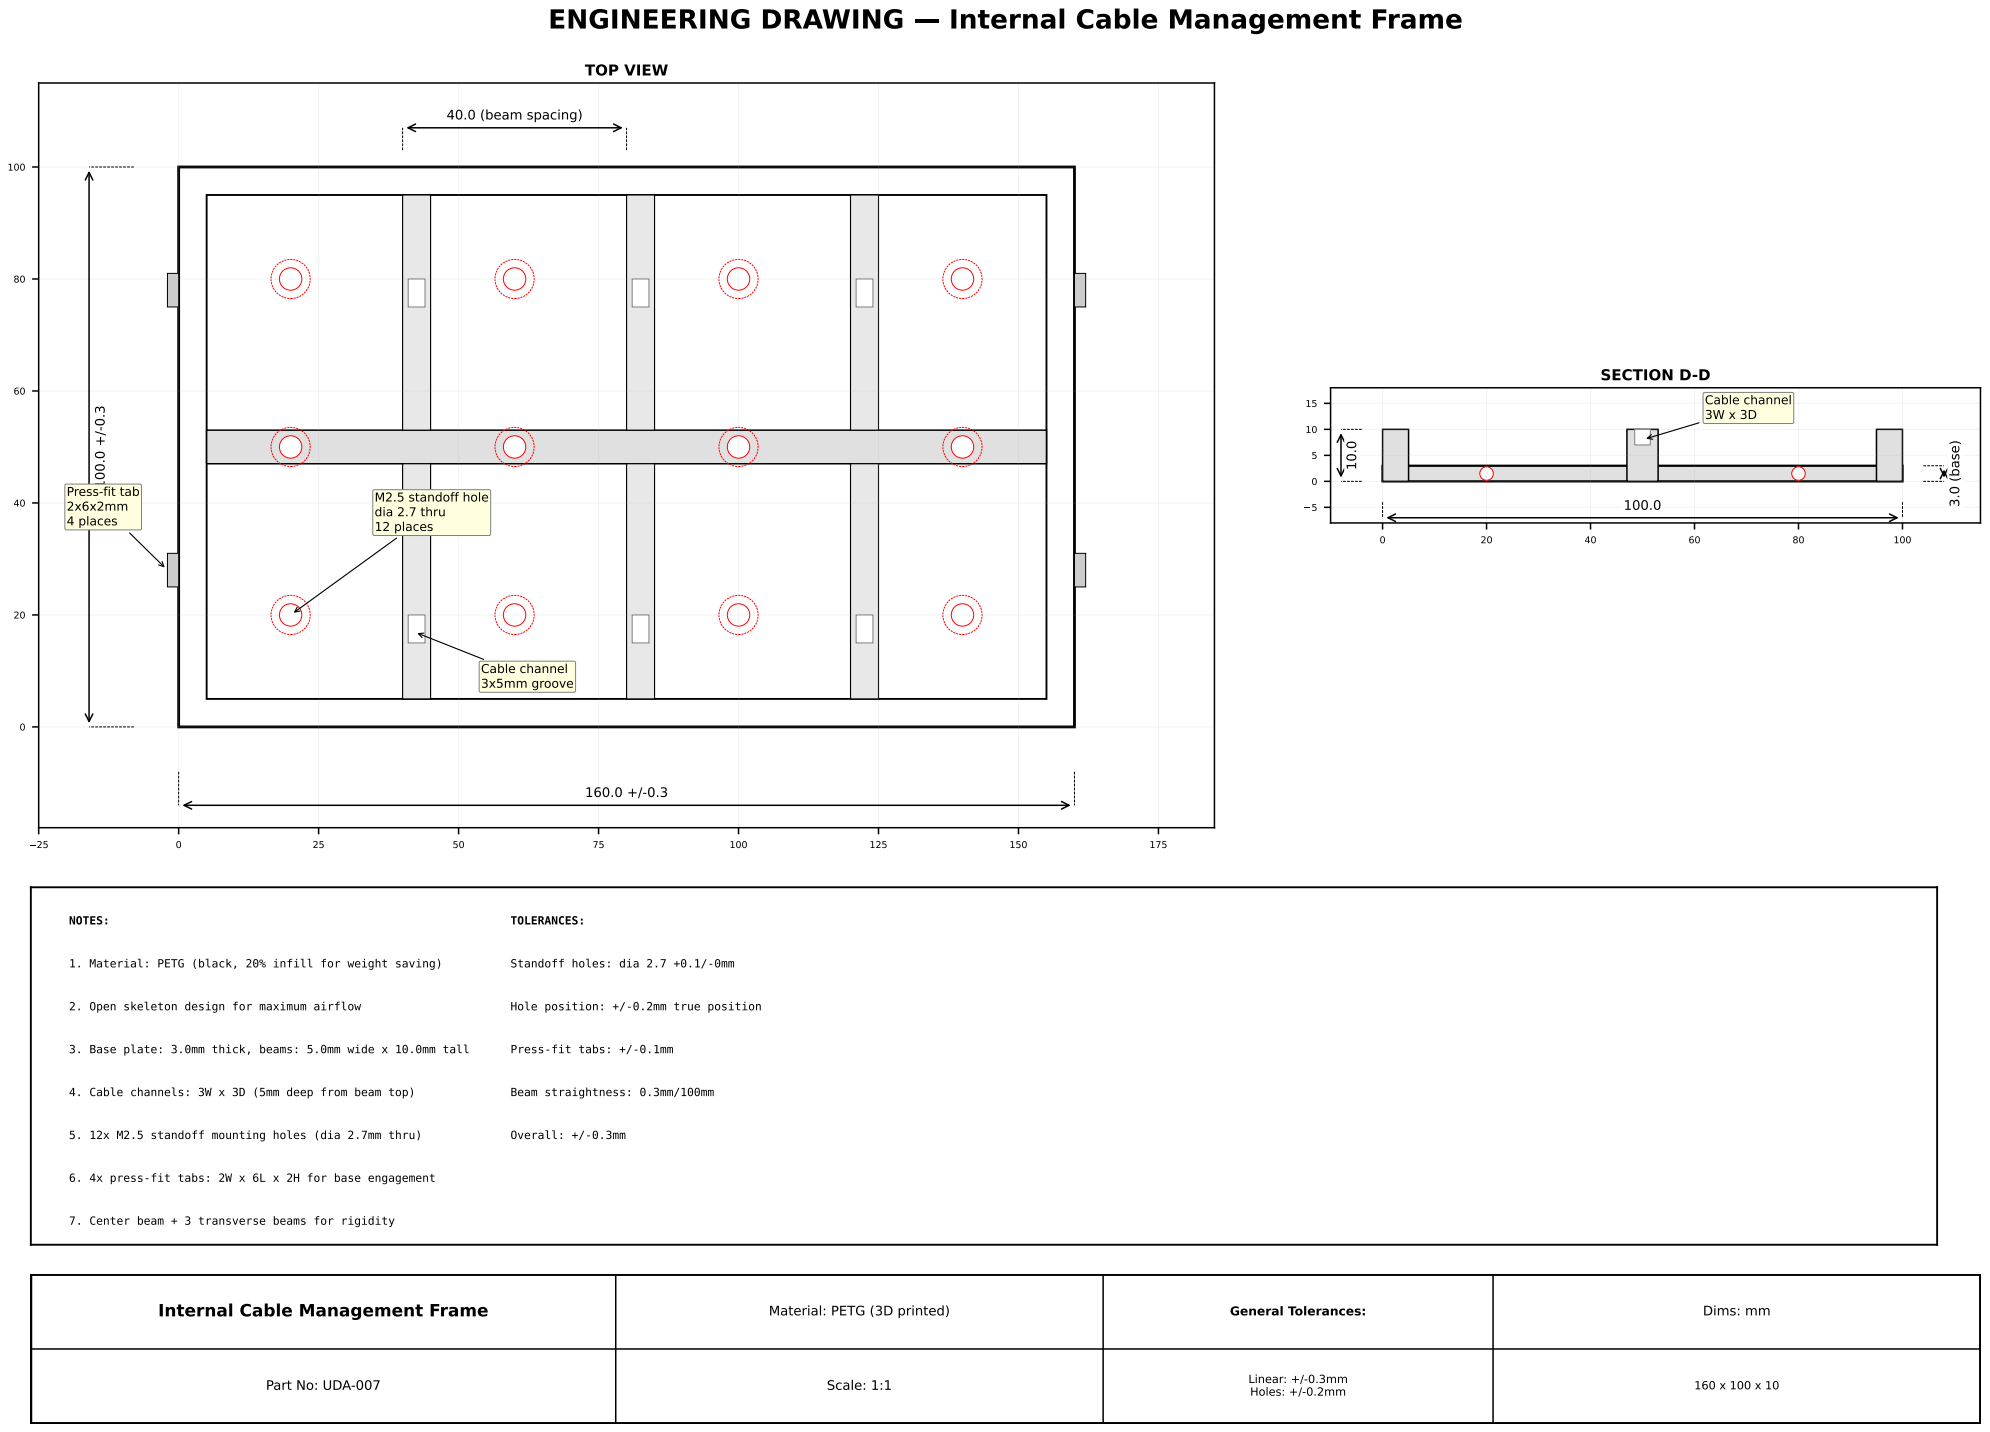
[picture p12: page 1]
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

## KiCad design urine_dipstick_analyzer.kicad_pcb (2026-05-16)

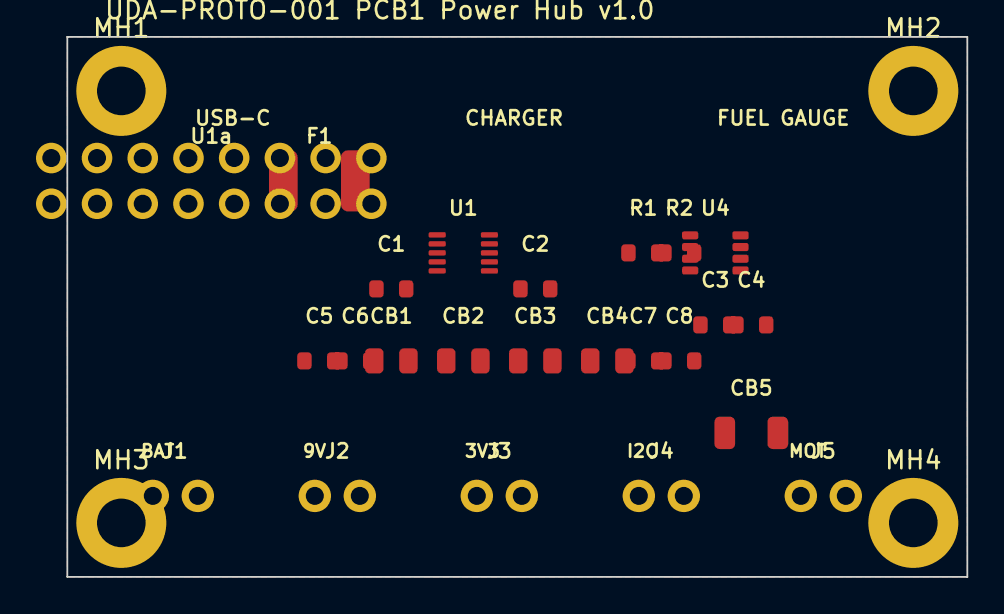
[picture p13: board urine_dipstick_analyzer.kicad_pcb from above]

Board: 2 copper layers, 50.0 x 30.0 mm, 28 parts (0 on the bottom side), 10 nets, no tracks yet.

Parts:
C1, C2, C3, C4, C5, C6, C7, C8: 100nF; C_0603_1608Metric
CB1, CB2, CB3, CB4: 10uF; C_0805_2012Metric
CB5: 100uF; C_1206_3216Metric
F1: 500mA_PTC; Fuse_1812_4532Metric
J1: BAT; JST_XH_B2B-XH-A_1x02_P2.50mm_Vertical
J2: 9V_OUT; JST_XH_B2B-XH-A_1x02_P2.50mm_Vertical
J3: 3V3_OUT; JST_XH_B2B-XH-A_1x02_P2.50mm_Vertical
J4: I2C_BUS; JST_XH_B2B-XH-A_1x02_P2.50mm_Vertical
J5: MOTOR_PWR; JST_XH_B2B-XH-A_1x02_P2.50mm_Vertical
MH1, MH2, MH3, MH4: MountingHole; MountingHole_2.7mm_M2.5
R1, R2: 4.7k; R_0603_1608Metric
U1: MCP73833; MSOP-10_3x3mm_P0.5mm
U1a: USB-C-BO; PinHeader_2x08_P2.54mm_Vertical
U4: MAX17048; SOT-23-8

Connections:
+3V3: C4.1, C6.1, CB3.1, J3.1, R1.2, R2.2
+5V: C7.1, CB4.1
+9V: C8.1, J2.1
CHRG_STAT: U1.1, U1.2
GND: C1.2, C2.2, C3.2, C4.2, C5.2, C6.2, C7.2, C8.2, CB1.2, CB2.2, CB3.2, CB4.2, CB5.2, J1.2, J2.2, J3.2, J5.2, U1.4, U1.7, U1.8, U1.9, U1a.1, U1a.2, U4.1, U4.3
SCL: J4.2, R2.1, U4.5
SDA: J4.1, R1.1, U4.4
VBAT: C2.1, C3.1, C5.1, CB2.1, J1.1, U1.5, U1.6, U4.2, U4.7
VBUS: C1.1, CB1.1, F1.1, F1.2, U1.10, U1a.3, U1a.4
VMOT: CB5.1, J5.1

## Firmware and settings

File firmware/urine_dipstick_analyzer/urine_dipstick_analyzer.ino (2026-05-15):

/*
 * URINE DIPSTICK ANALYZER v2.0 — ESP32-S3 Firmware
 *
 * Hardware: ESP32-S3-DevKitC-1-N8R8, OV2640 camera with CPL,
 *   ILI9341 2.4" TFT (320x240), SHT31, BH1750, DS3231 RTC,
 *   MAX17048 fuel gauge, A4988 stepper, NEMA 17,
 *   UV-C LED, heater film, barcode scanner, SD card
 *
 * Board: "ESP32S3 Dev Module" in Arduino IDE
 * PSRAM: "OPI PSRAM"
 * Partition: "Huge APP (3MB No OTA / 1MB SPIFFS)"
 *
 * Libraries required:
 *   - Adafruit ILI9341
 *   - Adafruit GFX
 *   - Adafruit SHT31
 *   - BH1750 (by Christopher Laws)
 *   - AccelStepper
 *   - ESP32 Camera driver (built-in with ESP32 board package)
 */

#include <Wire.h>
#include "config.h"
#include "display.h"
#include "sensors.h"
#include "stepper.h"
#include "heater.h"
#include "camera.h"
#include "analysis.h"
#include "storage.h"
#include "barcode.h"
#include "safety.h"
#include "leds.h"
#include "rtc.h"
#include "battery.h"

// ============================================================
// STATE MACHINE
// ============================================================
enum State {
    STATE_INIT,
    STATE_IDLE,
    STATE_SCAN_BARCODE,
    STATE_PREHEAT,
    STATE_TRAY_TO_CAPTURE,
    STATE_CAPTURE,
    STATE_ANALYZE,
    STATE_DISPLAY_RESULTS,
    STATE_LOG_RESULTS,
    STATE_TRAY_RETRACT,
    STATE_UV_STERILIZE,
    STATE_VENT,
    STATE_CALIBRATION,
    STATE_ERROR
};

// ============================================================
// GLOBAL OBJECTS
// ============================================================
Display        display;
Sensors        sensors;
TrayMotor      tray;
HeaterPID      heater;
Camera         cam;
Analysis       analysis;
Storage        storage;
BarcodeScanner barcode(Serial1);
SafetyManager  safety;
LEDController  leds;
RealTimeClock  rtc;
BatteryGauge   battery;

State currentState = STATE_INIT;
State prevState    = STATE_INIT;

// Button handling
volatile bool buttonPressed = false;
unsigned long buttonPressTime = 0;
unsigned long lastDebounce = 0;

// Test tracking
char currentPatientID[64] = "UNKNOWN";
int resultPage = 0;
uint32_t testNumber = 0;

// Calibration mode
bool calibrationMode = false;
int calPadIdx = 0;
int calLevel = 0;

// Error
char errorMsg[64] = {0};

// Status bar cache
char _timeStr[8] = "00:00";
float _battPct = 100.0f;
unsigned long _lastStatusUpdate = 0;

// Timing vars
static unsigned long _scanTimeout = 0;
static unsigned long _preheatStart = 0;
static unsigned long _ventStart = 0;

// ============================================================
// HELPERS
// ============================================================
void updateStatusInfo() {
    if (millis() - _lastStatusUpdate < 2000) return;
    _lastStatusUpdate = millis();

    rtc.read();
    rtc.formatTime(_timeStr, sizeof(_timeStr));

    battery.update();
    _battPct = battery.soc;

    if (battery.isCritical()) {
        display.showLowBattery(_battPct);
        leds.beepError();
        delay(2000);
    }
}

// ============================================================
// INTERRUPT
// ============================================================
void IRAM_ATTR onButtonPress() {
    unsigned long now = millis();
    if (now - lastDebounce > 200) {
        buttonPressed = true;
        buttonPressTime = now;
        lastDebounce = now;
    }
}

// ============================================================
// SETUP
// ============================================================
void setup() {
    Serial.begin(115200);
    Serial.println("\n=== Urine Dipstick Analyzer v2.0 ===\n");

    // I2C
    Wire.begin(I2C_SDA, I2C_SCL);

    // Button interrupt
    pinMode(PIN_BUTTON, INPUT_PULLUP);
    attachInterrupt(digitalPinToInterrupt(PIN_BUTTON), onButtonPress, FALLING);

    // Initialize all subsystems
    leds.begin();
    leds.rgbYellow();

    // TFT Display
    display.begin();
    display.showSplash();

    // RTC
    if (rtc.begin()) {
        rtc.formatTime(_timeStr, sizeof(_timeStr));
        Serial.printf("RTC: OK (%s)\n", _timeStr);
    } else {
        Serial.println("RTC: not found (using millis fallback)");
    }

    // Battery Gauge
    if (battery.begin()) {
        battery.update();
        _battPct = battery.soc;
        Serial.printf("Battery: %.0f%% (%.2fV)\n", _battPct, battery.voltage);
    } else {
        Serial.println("Battery gauge: not found");
    }

    // Sensors
    bool sht_ok = sensors.beginSHT31();
    bool bh_ok  = sensors.beginBH1750();
    Serial.printf("SHT31: %s, BH1750: %s\n", sht_ok ? "OK" : "FAIL", bh_ok ? "OK" : "FAIL");

    // Stepper
    tray.begin();

    // Heater
    heater.begin();

    // Camera
    if (!cam.begin()) {
        Serial.println("ERROR: Camera init failed");
        snprintf(errorMsg, sizeof(errorMsg), "Camera init failed");
        currentState = STATE_ERROR;
        return;
    }
    Serial.println("Camera: OK");

    // Analysis
    analysis.initDefaultROIs();
    if (analysis.loadCalibration()) {
        Serial.println("Calibration loaded from NVS");
    } else {
        Serial.println("No calibration found, using defaults");
    }

    // SD Card
    storage.setRTC(&rtc);
    if (storage.begin()) {
        Serial.println("SD Card: OK");
        testNumber = storage.getTestCount();
    } else {
        Serial.println("SD Card: not present (logging disabled)");
    }

    // Barcode scanner
    barcode.begin();
    Serial.println("Barcode scanner: OK");

    // Safety
    safety.begin();

    // Home the tray
    display.showStatus("Homing tray...");
    if (!tray.home()) {
        Serial.println("WARNING: Tray homing failed");
        display.showStatus("Tray home failed", "Continuing anyway...");
        delay(1500);
    } else {
        Serial.println("Tray: homed");
    }

    // Eject tray for strip insertion
    tray.moveToEject();
    while (!tray.isAtTarget()) tray.update();

    leds.rgbGreen();
    leds.beepSuccess();
    currentState = STATE_IDLE;
}

// ============================================================
// MAIN LOOP
// ============================================================
void loop() {
    tray.update();
    barcode.update();
    updateStatusInfo();

    switch (currentState) {
        case STATE_IDLE:            stateIdle();          break;
        case STATE_SCAN_BARCODE:    stateScanBarcode();   break;
        case STATE_PREHEAT:         statePreheat();       break;
        case STATE_TRAY_TO_CAPTURE: stateTrayToCapture(); break;
        case STATE_CAPTURE:         stateCapture();       break;
        case STATE_ANALYZE:         stateAnalyze();       break;
        case STATE_DISPLAY_RESULTS: stateDisplayResults(); break;
        case STATE_LOG_RESULTS:     stateLogResults();    break;
        case STATE_TRAY_RETRACT:    stateTrayRetract();   break;
        case STATE_UV_STERILIZE:    stateUVSterilize();   break;
        case STATE_VENT:            stateVent();          break;
        case STATE_CALIBRATION:     stateCalibration();   break;
        case STATE_ERROR:           stateError();         break;
        default: break;
    }

    prevState = currentState;
}

// ============================================================
// STATE HANDLERS
// ============================================================

void stateIdle() {
    if (prevState != STATE_IDLE) {
        display.showReady(_battPct, _timeStr, testNumber);
        leds.rgbGreen();
        strcpy(currentPatientID, "UNKNOWN");
    }

    // Check for long press -> calibration mode
    if (buttonPressed) {
        buttonPressed = false;

        if (digitalRead(PIN_BUTTON) == LOW) {
            unsigned long holdStart = millis();
            while (digitalRead(PIN_BUTTON) == LOW && (millis() - holdStart < 3000)) {
                delay(10);
            }
            if (millis() - holdStart >= 3000) {
                calPadIdx = 0;
                calLevel = 0;
                currentState = STATE_CALIBRATION;
                return;
            }
        }

        leds.beepShort();
        currentState = STATE_SCAN_BARCODE;
    }

    // Auto-trigger on barcode scan
    char code[64];
    if (barcode.read(code, sizeof(code))) {
        strncpy(currentPatientID, code, sizeof(currentPatientID) - 1);
        Serial.printf("Barcode scanned: %s\n", currentPatientID);
        display.showStatus("Patient ID:", currentPatientID);
        delay(1000);
        currentState = STATE_PREHEAT;
    }
}

void stateScanBarcode() {
    if (prevState != STATE_SCAN_BARCODE) {
        display.showScanBarcode(_battPct, _timeStr);
        barcode.triggerScan();
        _scanTimeout = millis();
    }

    char code[64];
    if (barcode.read(code, sizeof(code))) {
        strncpy(currentPatientID, code, sizeof(currentPatientID) - 1);
        display.showStatus("Patient ID:", currentPatientID);
        leds.beepShort();
        delay(800);
        currentState = STATE_PREHEAT;
        return;
    }

    if (buttonPressed || (millis() - _scanTimeout > 5000)) {
        buttonPressed = false;
        currentState = STATE_PREHEAT;
    }
}

void statePreheat() {
    if (prevState != STATE_PREHEAT) {
        leds.rgbYellow();
        heater.enable();
        _preheatStart = millis();
    }

    sensors.readAll();
    heater.update(sensors.trayTempC);

    if (millis() % 500 < 50) {
        display.showPreheat(sensors.trayTempC, HEATER_TARGET_C, _battPct, _timeStr);
    }

    if (heater.isAtTemp(sensors.trayTempC) || (millis() - _preheatStart > 60000)) {
        currentState = STATE_TRAY_TO_CAPTURE;
    }

    if (sensors.trayTempC > HEATER_OVERTEMP_C) {
        heater.disable();
        snprintf(errorMsg, sizeof(errorMsg), "Over-temp: %.1fC", sensors.trayTempC);
        currentState = STATE_ERROR;
    }
}

void stateTrayToCapture() {
    if (prevState != STATE_TRAY_TO_CAPTURE) {
        display.showMeasuring(1, 6, "Moving tray to capture position");
        tray.moveToCapture();
    }

    if (tray.isAtTarget()) {
        delay(500);
        currentState = STATE_CAPTURE;
    }
}

void stateCapture() {
    if (prevState != STATE_CAPTURE) {
        display.showMeasuring(2, 6, "Capturing strip image");
        leds.rgbBlue();
    }

    sensors.readAll();
    if (!sensors.isAmbientLightOK()) {
        display.showStatus("Warning:", "High ambient light!");
        delay(1000);
    }

    leds.whiteLedOn();
    delay(200);

    camera_fb_t *discard = cam.capture();
    cam.release(discard);
    delay(100);

    analysis.captureWhiteReference(cam);

    display.showMeasuring(3, 6, "White reference captured");
    currentState = STATE_ANALYZE;
}

void stateAnalyze() {
    if (prevState != STATE_ANALYZE) {
        display.showMeasuring(4, 6, "Analyzing colorimetry");
    }

    bool ok = analysis.analyzeStrip(cam);
    leds.whiteLedOff();

    if (!ok) {
        snprintf(errorMsg, sizeof(errorMsg), "Image analysis failed");
        currentState = STATE_ERROR;
        return;
    }

    Serial.println("\n--- RESULTS ---");
    for (int i = 0; i < NUM_PADS; i++) {
        Serial.printf("  %-4s: %.1f %s (%s) [H=%.0f S=%.2f V=%.2f]\n",
            PAD_NAMES_ARR[i],
            analysis.readings[i].concentration,
            PAD_UNITS[i],
            analysis.readings[i].catLabel,
            analysis.readings[i].h,
            analysis.readings[i].s,
            analysis.readings[i].v);
    }
    Serial.println("---------------\n");

    leds.beepSuccess();
    display.showMeasuring(5, 6, "Analysis complete");
    delay(500);
    resultPage = 0;
    currentState = STATE_DISPLAY_RESULTS;
}

void stateDisplayResults() {
    if (prevState != STATE_DISPLAY_RESULTS || prevState == currentState) {
        leds.rgbGreen();

        float vals[NUM_PADS];
        const char* cats[NUM_PADS];
        for (int i = 0; i < NUM_PADS; i++) {
            vals[i] = analysis.readings[i].concentration;
            cats[i] = analysis.readings[i].catLabel;
        }
        display.showResults(PAD_NAMES_ARR, vals, cats, NUM_PADS, resultPage, _battPct, _timeStr);
    }

    if (buttonPressed) {
        buttonPressed = false;
        resultPage++;
        int maxPages = (NUM_PADS + 4) / 5;
        if (resultPage >= maxPages) {
            currentState = STATE_LOG_RESULTS;
        } else {
            float vals[NUM_PADS];
            const char* cats[NUM_PADS];
            for (int i = 0; i < NUM_PADS; i++) {
                vals[i] = analysis.readings[i].concentration;
                cats[i] = analysis.readings[i].catLabel;
            }
            display.showResults(PAD_NAMES_ARR, vals, cats, NUM_PADS, resultPage, _battPct, _timeStr);
        }
    }
}

void stateLogResults() {
    if (prevState != STATE_LOG_RESULTS) {
        display.showMeasuring(6, 6, "Saving results to SD");
    }

    sensors.readAll();
    storage.logResult(currentPatientID, analysis.readings,
                      sensors.temperature, sensors.humidity,
                      sensors.lux, sensors.trayTempC,
                      _battPct, battery.voltage);
    storage.incrementTestCount();
    testNumber++;

    heater.disable();
    currentState = STATE_TRAY_RETRACT;
}

void stateTrayRetract() {
    if (prevState != STATE_TRAY_RETRACT) {
        display.showStatus("Retracting tray...");
        tray.moveToHome();
    }

    if (tray.isAtTarget()) {
        currentState = STATE_UV_STERILIZE;
    }
}

void stateUVSterilize() {
    if (prevState != STATE_UV_STERILIZE) {
        display.showUVSterilizing(0, _battPct, _timeStr);
        leds.rgbPurple();

        if (!safety.startUV()) {
            display.showStatus("UV skipped:", "Tray not sealed");
            delay(1500);
            currentState = STATE_VENT;
            return;
        }
    }

    int progress = safety.updateUV();
    if (progress < 0) {
        display.showStatus("UV interrupted!", "Tray opened");
        leds.beepError();
        delay(1500);
        currentState = STATE_VENT;
        return;
    }

    display.showUVSterilizing(progress, _battPct, _timeStr);

    if (progress >= 100) {
        display.showStatus("UV complete");
        delay(500);
        currentState = STATE_VENT;
    }
}

void stateVent() {
    if (prevState != STATE_VENT) {
        leds.fanOn();
        _ventStart = millis();
    }

    sensors.readAll();
    display.showVenting(sensors.humidity, _battPct, _timeStr);

    if ((millis() - _ventStart > 10000) || sensors.isHumidityOK()) {
        leds.fanOff();

        tray.moveToEject();
        while (!tray.isAtTarget()) tray.update();

        currentState = STATE_IDLE;
    }
}

void stateCalibration() {
    if (prevState != STATE_CALIBRATION) {
        display.showCalibration(calPadIdx, calLevel, PAD_NAMES_ARR[calPadIdx], _battPct, _timeStr);
        leds.rgbPurple();
        leds.beepLong();
    }

    if (buttonPressed) {
        buttonPressed = false;

        leds.whiteLedOn();
        delay(300);

        camera_fb_t *discard = cam.capture();
        cam.release(discard);
        delay(100);

        analysis.captureWhiteReference(cam);
        camera_fb_t *fb = cam.capture();
        if (fb) {
            float r, g, b;
            cam.getROI_RGB(fb, analysis.rois[calPadIdx].x, analysis.rois[calPadIdx].y,
                           analysis.rois[calPadIdx].w, analysis.rois[calPadIdx].h,
                           r, g, b);
            cam.release(fb);

            float h, s, v;
            Camera::rgb_to_hsv(r, g, b, h, s, v);

            Serial.printf("CAL [%s] Level %d: R=%.0f G=%.0f B=%.0f H=%.0f S=%.2f V=%.2f\n",
                PAD_NAMES_ARR[calPadIdx], calLevel, r, g, b, h, s, v);

            char logMsg[128];
            snprintf(logMsg, sizeof(logMsg), "CAL %s L%d: H=%.1f S=%.2f V=%.2f",
                     PAD_NAMES_ARR[calPadIdx], calLevel, h, s, v);
            storage.logCalibrationEvent(logMsg);

            leds.beepShort();
        }

        leds.whiteLedOff();

        calLevel++;
        if (calLevel >= CAL_LEVELS) {
            calLevel = 0;
            calPadIdx++;
            if (calPadIdx >= NUM_PADS) {
                analysis.saveCalibration();
                storage.logCalibrationEvent("Calibration complete");
                display.showStatus("Calibration", "SAVED!");
                leds.beepSuccess();
                delay(2000);
                calPadIdx = 0;
                calLevel = 0;
                currentState = STATE_IDLE;
                return;
            }
        }

        display.showCalibration(calPadIdx, calLevel, PAD_NAMES_ARR[calPadIdx], _battPct, _timeStr);
    }
}

void stateError() {
    if (prevState != STATE_ERROR) {
        display.showError(errorMsg, _battPct, _timeStr);
        leds.rgbRed();
        leds.beepError();
        heater.disable();
        leds.whiteLedOff();
        safety.stopUV();
        leds.fanOff();
        Serial.printf("ERROR: %s\n", errorMsg);
    }

    if (buttonPressed) {
        buttonPressed = false;
        currentState = STATE_IDLE;
    }
}

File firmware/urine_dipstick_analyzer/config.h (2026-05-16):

#pragma once

// ============================================================
// PIN DEFINITIONS — ESP32-S3-DevKitC-1-N8R8
// ============================================================

// --- Camera (OV2640 DVP) ---
#define CAM_PIN_PWDN   -1
#define CAM_PIN_RESET  -1
#define CAM_PIN_XCLK   10
#define CAM_PIN_SIOD   11
#define CAM_PIN_SIOC   12
#define CAM_PIN_D7     13
#define CAM_PIN_D6     14
#define CAM_PIN_D5      9
#define CAM_PIN_D4     48
#define CAM_PIN_D3     47
#define CAM_PIN_D2     46
#define CAM_PIN_D1     45
#define CAM_PIN_D0      3
#define CAM_PIN_VSYNC  35
#define CAM_PIN_HREF   36
#define CAM_PIN_PCLK   37

// --- I2C Bus (shared: TFT touch, SHT31, BH1750, DS3231, MAX17048) ---
#define I2C_SDA        19
#define I2C_SCL        18

// --- SPI Bus (SD Card + TFT Display) ---
#define SD_MISO        38
#define SD_MOSI        39
#define SD_SCK         40
#define SD_CS          41

// --- TFT Display (ILI9341 2.4" 320x240, SPI) ---
#define TFT_CS         15
#define TFT_DC         16
#define TFT_RST        -1
#define TFT_MOSI       SD_MOSI
#define TFT_SCK        SD_SCK
#define TFT_MISO       SD_MISO
#define TFT_BL         -1

// --- Stepper Motor (A4988 Driver) ---
#define STEPPER_STEP    4
#define STEPPER_DIR     5
#define STEPPER_ENABLE -1

// --- MOSFET Gates ---
#define PIN_FAN_GATE    2
#define PIN_HEATER_GATE 44  // was 4 (collided with STEPPER_STEP); UART0 RX repurposed, debug via USB-CDC
#define PIN_UV_GATE     20

// --- White LED Array ---
#define PIN_WHITE_LED    6

// --- RGB Status LED (Common Anode, active LOW) ---
#define PIN_RGB_RED      7
#define PIN_RGB_GREEN    8
#define PIN_RGB_BLUE    -1  // dropped: GPIO 17 reassigned to BARCODE_RX; use TFT for status

// --- User Input ---
#define PIN_BUTTON       1

// --- Safety Interlock (Reed Switch) ---
#define PIN_REED_SWITCH 21

// --- Limit Switch (Tray Home) ---
#define PIN_LIMIT_SW    42

// --- Buzzer ---
#define PIN_BUZZER      43

// --- Barcode Scanner (UART) ---
#define BARCODE_TX      0   // was 16 (collided with TFT_DC); strapping pin, UART idle HIGH is compatible
#define BARCODE_RX      17  // was 18 (collided with I2C_SCL); reclaimed from RGB_BLUE (D2 dropped)

// --- Thermistor (ADC) ---
#define PIN_THERMISTOR  A0

// ============================================================
// I2C ADDRESSES
// ============================================================
#define SHT31_ADDR      0x44
#define BH1750_ADDR     0x23
#define DS3231_ADDR     0x68
#define MAX17048_ADDR   0x36

// ============================================================
// BATTERY THRESHOLDS
// ============================================================
#define BATT_LOW_PCT    15
#define BATT_CRITICAL_PCT 5

// ============================================================
// SYSTEM CONSTANTS
// ============================================================

// Stepper motor
#define STEPS_PER_REV       200
#define MICROSTEPS          16
#define LEAD_SCREW_PITCH_MM 8.0f
#define TRAY_TRAVEL_MM      80.0f
#define STEPPER_MAX_SPEED   1000
#define STEPPER_ACCEL       500
#define HOME_SPEED          200

// Heater PID
#define HEATER_TARGET_C     37.0f
#define HEATER_KP           20.0f
#define HEATER_KI           1.0f
#define HEATER_KD           5.0f
#define HEATER_MAX_DUTY     200
#define HEATER_OVERTEMP_C   45.0f

// UV sterilization
#define UV_CYCLE_MS         30000

// Thermistor
#define THERM_NOMINAL_R     10000.0f
#define THERM_NOMINAL_T     25.0f
#define THERM_BCOEFF        3950.0f
#define THERM_SERIES_R      10000.0f

// Camera
#define CAM_WIDTH           320
#define CAM_HEIGHT          240

// Dipstick analysis
#define NUM_PADS            10
#define PAD_NAMES           {"GLU","PRO","pH","SG","KET","BIL","URO","BLD","NIT","LEU"}

// Pad ROI positions (x, y, width, height) in captured image
// These are calibrated for the specific tray/channel geometry
#define PAD_ROI_W           20
#define PAD_ROI_H           12

// Calibration
#define CAL_LEVELS          6
#define NVS_NAMESPACE       "dipstick_cal"

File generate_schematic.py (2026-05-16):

#!/usr/bin/env python3
"""
Generate a KiCad 8 schematic (.kicad_sch) for Urine Dipstick Analyzer v2.0.

FIXED VERSION - uses proper lib_symbols with real pin definitions so that:
 1. Decoupling caps have explicit wire connections to IC pins (not floating net labels)
 2. OV2640 camera <-> ESP32-S3 data bus has visible wires via net labels on both ends
 3. FAN1 is a proper 2-pin component wired to Q3 drain and 5V

All coordinates snap to 2.54mm grid.
"""

import uuid
import os


# ---------------------------------------------------------------------------
# Primitives
# ---------------------------------------------------------------------------

def uid():
    return str(uuid.uuid4())


def snap(v):
    return round(v / 2.54) * 2.54


def wire(x1, y1, x2, y2):
    x1, y1, x2, y2 = snap(x1), snap(y1), snap(x2), snap(y2)
    return (
        f'  (wire (pts (xy {x1:.2f} {y1:.2f}) (xy {x2:.2f} {y2:.2f}))'
        f' (stroke (width 0) (type default)) (uuid "{uid()}"))'
    )


def netlabel(name, x, y, angle=0):
    x, y = snap(x), snap(y)
    return (
        f'  (label "{name}" (at {x:.2f} {y:.2f} {angle})'
        f' (fields_autoplaced yes)'
        f' (effects (font (size 1.27 1.27)))'
        f' (uuid "{uid()}")'
        f' (property "Intersheet References" "" (at 0 0 0)'
        f'  (effects (font (size 1.27 1.27)) hide)))'
    )


def glabel(name, x, y, shape="input", angle=0):
    x, y = snap(x), snap(y)
    return (
        f'  (global_label "{name}" (shape {shape}) (at {x:.2f} {y:.2f} {angle})'
        f' (fields_autoplaced yes)'
        f' (effects (font (size 1.27 1.27)))'
        f' (uuid "{uid()}")'
        f' (property "Intersheet References" "" (at 0 0 0)'
        f'  (effects (font (size 1.27 1.27)) hide)))'
    )


def txt(s, x, y, size=1.27, bold=False):
    x, y = snap(x), snap(y)
    b = " bold" if bold else ""
    return (
        f'  (text "{s}" (at {x:.2f} {y:.2f} 0)'
        f' (effects (font (size {size} {size}){b}))'
        f' (uuid "{uid()}"))'
    )


def section_box(title, x1, y1, x2, y2):
    x1, y1, x2, y2 = snap(x1), snap(y1), snap(x2), snap(y2)
    lines = []
    lines.append(
        f'  (polyline (pts (xy {x1:.2f} {y1:.2f}) (xy {x2:.2f} {y1:.2f})'
        f' (xy {x2:.2f} {y2:.2f}) (xy {x1:.2f} {y2:.2f}) (xy {x1:.2f} {y1:.2f}))'
        f' (stroke (width 0.254) (type dash)) (uuid "{uid()}"))'
    )
    lines.append(txt(title, (x1 + x2) / 2, y1 + 4.0, 2.5, bold=True))
    return lines


# ---------------------------------------------------------------------------
# IC symbol placer - returns (element_str, pin_dict)
# pin_dict maps pin_name -> (abs_x, abs_y)
#
# left_pins:  list of (name, pin_number)  - tips point LEFT, angle=0
# right_pins: list of (name, pin_number)  - tips point RIGHT, angle=180
# body_w, body_h: full body width/height in mm
# pin_len: pin stub length
# ---------------------------------------------------------------------------

def place_ic(lib_id, ref, value, px, py,
             left_pins, right_pins,
             body_w=20.32, body_h=None,
             pin_len=5.08, pin_spacing=2.54):
    px, py = snap(px), snap(py)
    n = max(len(left_pins), len(right_pins))
    if body_h is None:
        body_h = snap((n + 1) * pin_spacing)

    hw = body_w / 2.0
    hh = body_h / 2.0

    # Build pin elements list
    pin_dict = {}
    pin_els = []

    # Left pins: tip x = px - hw - pin_len, y increments from top
    for i, (pname, pnum) in enumerate(left_pins):
        sym_y = hh - pin_spacing - i * pin_spacing
        abs_x = px - hw - pin_len
        abs_y = py + sym_y
        pin_dict[pname] = (snap(abs_x), snap(abs_y))
        pin_els.append(f'  (pin "{pnum}" (uuid "{uid()}"))')

    # Right pins: tip x = px + hw + pin_len
    for i, (pname, pnum) in enumerate(right_pins):
        sym_y = hh - pin_spacing - i * pin_spacing
        abs_x = px + hw + pin_len
        abs_y = py + sym_y
        pin_dict[pname] = (snap(abs_x), snap(abs_y))
        pin_els.append(f'  (pin "{pnum}" (uuid "{uid()}"))')

    pins_str = "\n".join(pin_els)

    n_left = len(left_pins) + 1
    n_right = len(right_pins) + 1

    elem = (
        f'  (symbol (lib_id "{lib_id}") (at {px:.2f} {py:.2f} 0) (unit 1)\n'
        f'    (property "Reference" "{ref}" (at {px:.2f} {py - hh - 3.81:.2f} 0)'
        f' (effects (font (size 1.27 1.27))))\n'
        f'    (property "Value" "{value}" (at {px:.2f} {py - hh - 1.27:.2f} 0)'
        f' (effects (font (size 1.27 1.27))))\n'
        f'{pins_str}\n'
        f'  )'
    )
    return elem, pin_dict


# ---------------------------------------------------------------------------
# Capacitor placer (custom:C - vertical, 2-pin)
# Pin 1 (top) tip: (cx, cy - 3.81)
# Pin 2 (bot) tip: (cx, cy + 3.81)
# ---------------------------------------------------------------------------

def place_cap(ref, value, cx, cy):
    cx, cy = snap(cx), snap(cy)
    u = uid()
    elem = (
        f'  (symbol (lib_id "custom:C") (at {cx:.2f} {cy:.2f} 0) (unit 1)\n'
        f'    (property "Reference" "{ref}" (at {cx + 1.27:.2f} {cy - 1.27:.2f} 0)'
        f' (effects (font (size 1.016 1.016)) (justify left)))\n'
        f'    (property "Value" "{value}" (at {cx + 1.27:.2f} {cy + 1.27:.2f} 0)'
        f' (effects (font (size 1.016 1.016)) (justify left)))\n'
        f'    (pin "1" (uuid "{uid()}"))\n'
        f'    (pin "2" (uuid "{uid()}"))\n'
        f'  )'
    )
    pin1 = (cx, cy - 3.81)   # top
    pin2 = (cx, cy + 3.81)   # bottom
    return elem, pin1, pin2


# ---------------------------------------------------------------------------
# Resistor placer (custom:R - vertical, 2-pin)
# Pin 1 (top) tip: (rx, ry - 3.81)
# Pin 2 (bot) tip: (rx, ry + 3.81)
# ---------------------------------------------------------------------------

def place_res(ref, value, rx, ry):
    rx, ry = snap(rx), snap(ry)
    elem = (
        f'  (symbol (lib_id "custom:R") (at {rx:.2f} {ry:.2f} 0) (unit 1)\n'
        f'    (property "Reference" "{ref}" (at {rx + 1.27:.2f} {ry - 1.27:.2f} 0)'
        f' (effects (font (size 1.016 1.016)) (justify left)))\n'
        f'    (property "Value" "{value}" (at {rx + 1.27:.2f} {ry + 1.27:.2f} 0)'
        f' (effects (font (size 1.016 1.016)) (justify left)))\n'
        f'    (pin "1" (uuid "{uid()}"))\n'
        f'    (pin "2" (uuid "{uid()}"))\n'
        f'  )'
    )
    pin1 = (rx, ry - 3.81)
    pin2 = (rx, ry + 3.81)
    return elem, pin1, pin2


# ---------------------------------------------------------------------------
# MOSFET placer (custom:NMOSFET)
# G tip: (mx - 7.62, my)
# D tip: (mx,       my - 5.08)
# S tip: (mx,       my + 5.08)
# ---------------------------------------------------------------------------
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

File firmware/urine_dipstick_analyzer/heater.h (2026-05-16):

#pragma once
#include "config.h"

class HeaterPID {
public:
    float setpoint = HEATER_TARGET_C;
    float kp = HEATER_KP;
    float ki = HEATER_KI;
    float kd = HEATER_KD;

    bool enabled = false;
    int dutyCycle = 0;

    static constexpr int LEDC_CH = 0;
    void begin() {
        ledcSetup(LEDC_CH, 1000, 8);
        ledcAttachPin(PIN_HEATER_GATE, LEDC_CH);
        ledcWrite(LEDC_CH, 0);
    }

    void enable() {
        enabled = true;
        _integral = 0;
        _lastError = 0;
        _lastTime = millis();
    }

    void disable() {
        enabled = false;
        dutyCycle = 0;
        ledcWrite(LEDC_CH,0);
    }

    bool update(float currentTemp) {
        if (!enabled) return false;

        if (currentTemp > HEATER_OVERTEMP_C) {
            disable();
            return false;
        }

        unsigned long now = millis();
        float dt = (now - _lastTime) / 1000.0f;
        if (dt < 0.1f) return true;
        _lastTime = now;

        float error = setpoint - currentTemp;
        _integral += error * dt;
        _integral = constrain(_integral, -50, 50);
        float derivative = (error - _lastError) / dt;
        _lastError = error;

        float output = kp * error + ki * _integral + kd * derivative;
        dutyCycle = constrain((int)output, 0, HEATER_MAX_DUTY);
        ledcWrite(LEDC_CH,dutyCycle);

        return true;
    }

    bool isAtTemp(float currentTemp, float tolerance = 0.5f) {
        return abs(currentTemp - setpoint) < tolerance;
    }

private:
    float _integral = 0;
    float _lastError = 0;
    unsigned long _lastTime = 0;
};

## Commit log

2026-05-15 Initial commit: Urine Dipstick Analyzer CAD, schematic, and build report
    Camera-based urine dipstick analyzer for Indian market using ESP32-S3.
    Includes 7 mechanical CAD components (STEP+STL), KiCad 8 schematic with
    full circuit (51 symbols, 7 subsystems), and comprehensive build report
    covering science, BOM, assembly, firmware, calibration, and CDSCO regulatory.
    Components: enclosure base, cover, dipstick tray, camera/LED mount,
    scanner mount, vent grill, and cable management frame.
    [camera_led_mount.step, camera_led_mount.stl, enclosure_cover.step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]
2026-05-15 Add ESP32-S3 firmware, engineering drawings, and UX upgrades
    Complete Arduino firmware with 13-state state machine for the urine
    dipstick analyzer. Includes v2.0 UX upgrades: 2.4 inch ILI9341 TFT color
    display with color-coded results, DS3231 RTC for real timestamps,
    and MAX17048 battery fuel gauge with low-battery warnings.
    Also adds 7 engineering drawing PDFs with dimensions and tolerances,
    build report in HTML/PDF formats, and the drawing generator script.
    [config.h, display.h, generate_drawings.py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]
2026-05-15 Fix schematic pin overlaps and add BOM/render tools
    - Widen ESP32 block to 76.20mm, all modules to 38-43mm
    - Increase pin spacing to 7.62mm with wire stubs for label clearance
    - Adjust section coordinates to prevent block collisions
    - Add BOM CSV/PDF generator with 72-part costed bill of materials
    - Add matplotlib schematic renderer for PNG preview
    [BOM.csv, urine_dipstick_analyzer.kicad_sch]
2026-05-15 Add professional section boxes and fix schematic layout
    - Dashed boundary rectangles around each section (like reference schematic)
    - Layout instructions text block at bottom
    - Fixed section spacing to prevent overlap between Motor/UI and Display/Safety
    - ESP32 pins fully readable with 7.62mm spacing and 76.20mm box width
    [urine_dipstick_analyzer.kicad_sch]
2026-05-15 BOM v2: add manufacturer part numbers for all components
    - Every electrical component now has a specific MPN (e.g. MCP73833-FCI/UN,
    IRLZ44NPBF, GRM188R71C104KA01D, RC0603FR-074K7L)
    - Added MPN column to PDF generator
    - DigiKey/Mouser-sourceable MPNs for all passives (Yageo, Murata)
    - Specific sensor ICs: SHT31-DIS-B2.5KS, BH1750FVI-TR, DS3231SN
    - 111 parts total, $329.95 estimated cost
    [BOM.csv]
2026-05-16 Fix KiCad schematic: proper IC symbols with wired connections
    - Complete rewrite of generate_schematic.py with real lib_symbols
    - All ICs now have proper pin definitions (not just wire rectangles)
    - Decoupling caps explicitly wired to IC VDD/GND pins
    - Fan (FAN1) added as 2-terminal component wired to Q3 drain + 5V
    - OV2640 camera data bus (D0-D7) connected to ESP32 via net labels
    - Fixed KiCad 10 subsymbol naming (no library prefix in sub-symbol names)
    - Stripped non-ASCII characters for KiCad parser compatibility
    - 57 symbol instances, 71 wires, 93 net labels, 94 global labels
    [urine_dipstick_analyzer.kicad_sch]
2026-05-16 Add prototype assets: PCB, gerbers, PlatformIO, calibration, assembly guide
    - generate_pcb.py: programmatic KiCad 10 PCB generator for the 50x30mm
    power-distribution board (PCB1) with footprints, mounting holes, GND
    zones on both layers. Routing left to user.
    - urine_dipstick_analyzer.kicad_pcb: generated PCB (unrouted).
    - gerbers/ + gerbers.zip: kicad-cli exported gerbers + drill, fab-ready
    once the user hand-routes the remaining nets.
    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
    [urine_dipstick_analyzer-B_Courtyard.gbr, urine_dipstick_analyzer-B_Cu.gbl, urine_dipstick_analyzer-B_Fab.gbr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]
2026-05-16 Fix GPIO collisions in firmware config
    - HEATER_GATE: GPIO 47 → 4 (was colliding with CAM_D3)
    - BARCODE_RX: GPIO 3 → 18 (was colliding with CAM_D0)
    - BARCODE_TX: GPIO 44 → 16 (clear UART0 conflict)
    Update ASSEMBLY_GUIDE.md harness notes and troubleshooting accordingly.
    All 27 GPIO assignments now unique.
    [config.h]
2026-05-16 Route PCB, add README+LICENSE, verify firmware build
    [urine_dipstick_analyzer-B_Courtyard.gbr, urine_dipstick_analyzer-B_Cu.gbl, urine_dipstick_analyzer-B_Fab.gbr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]
2026-05-16 Fix firmware build: use LEDC v2 API for Arduino-ESP32 v2.x
    heater.h was calling ledcAttach (v3 API). Reverted to v2:
    ledcSetup + ledcAttachPin + ledcWrite by channel.
    Build succeeds: RAM 8.1%, Flash 14.2%, firmware.bin generated.
    Note: pip3 install --user intelhex required on build host.
    [heater.h]
2026-05-16 Add STATUS.md: honest accounting of working vs unfinished assets
    DRC/ERC findings:
    - Schematic: 252 ERC violations (unconnected pins on auto-placed passives)
    - PCB: 75 DRC violations (footprint mismatches, mask bridges) + 51 unrouted nets
    - Generator approach hit its limit — PCB needs human KiCad work
    Stripped the bad autorouted tracks (46 segments, 11 vias) since they
    introduced shorts. PCB is back to a clean unrouted placement.
    Gerbers regenerated but flagged not-manufacturable until DRC clean.
    Committed reports (drc_report.txt, erc_report.txt) so reviewer can see
    exact issue list. STATUS.md documents recommended path forward.
    [urine_dipstick_analyzer-B_Courtyard.gbr, urine_dipstick_analyzer-B_Cu.gbl, urine_dipstick_analyzer-B_Fab.gbr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]
2026-05-16 Add CDSCO MDR 2017 Class B regulatory dossier
2026-05-16 Add ESP32+BH1750 production-grade reference design
    A complete USB-C powered ESP32-WROOM-32E + BH1750FVI ambient light sensor
    reference design that demonstrates proper EE practices: USB-C protection
    stack (USBLC6 ESD, SMAJ5.0 TVS, polyfuse, AO3401A reverse-polarity PMOS),
    AMS1117-3.3 LDO with 22uF/100nF input+output decoupling, BLM18PG121
    ferrite bead feeding a clean ESP32 VDD33 rail, correct boot strapping
    (GPIO0 PU+button, GPIO2 PD, GPIO15 PU), EN reset RC (10k+100nF, 1ms tau),
    6-pin UART programming header, and 4.7k I2C pull-ups with DNP series-RC
    EMI filter on the BH1750 bus.
    Includes generator script, ERC-clean schematic (0 errors, 2 cosmetic
    warnings), full BOM with real MPNs, ~3000-wo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
    [BOM.csv, esp32_light_sensor.kicad_sch]
2026-05-16 Resolve GPIO collisions on ESP32-S3-DevKitC-1-N8R8
    GPIOs 26-37 are consumed by OPI flash + PSRAM on the -N8R8 variant
    and are NOT broken out, so the only spare pins are GPIO 0 and 44.
    Reassigned:
    - PIN_HEATER_GATE: 4 -> 44 (was colliding with STEPPER_STEP;
    UART0 RX repurposed, debug via USB-CDC)
    - BARCODE_TX: 16 -> 0 (was colliding with TFT_DC;
    strapping pin, UART idle HIGH is safe)
    - BARCODE_RX: 18 -> 17 (was colliding with I2C_SCL;
    reclaimed from RGB_BLUE)
    - PIN_RGB_BLUE: 17 -> -1 (dropped; status indication via TFT)
    Firmware still compiles: RAM 8.1%, Flash 14.2%.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
    [config.h]
2026-05-16 Add GitHub Actions CI: auto-build firmware on push
    Runs pio build on Ubuntu for ESP32-S3-DevKitC-1 on every push that
    touches firmware/. Caches the PlatformIO toolchain (~600 MB) to keep
    subsequent runs under 90 seconds. Uploads firmware.bin as a 30-day
    artifact for easy flashing.
    Catches regressions in pin assignments, library bumps, and config
    changes without needing local PIO setup.
